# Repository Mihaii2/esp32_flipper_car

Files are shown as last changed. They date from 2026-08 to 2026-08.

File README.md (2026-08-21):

# Flipper Car ROS 2 Workspace

A dual-mode, auto-inverting RC flipper car controlled via ESP32, TC1508 dual H-bridge motor driver, and ROS 2 Jazzy.

<div align="center">
  <table>
    <tr>
      <td align="center" width="33%">
        Live Demo
      </td>
      <td align="center" width="33%">
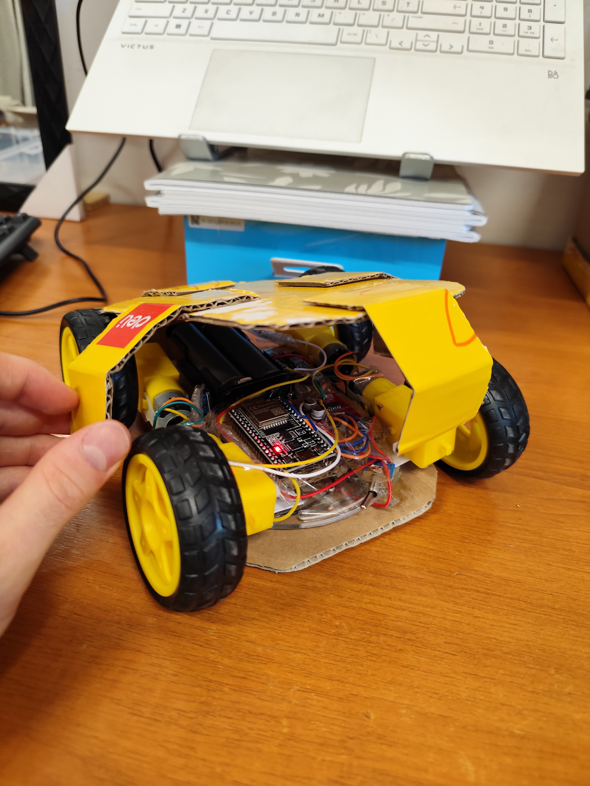
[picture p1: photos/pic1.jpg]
Chassis Top
        
      </td>
      <td align="center" width="33%">
        Chassis Detail
      </td>
    </tr>
  </table>
</div>

> **🛠 Engineering Revision Note (v1.0 → v2.0):**  
> * **v1.0 (Initial Prototype):** Originally designed around discrete low-side N-channel MOSFETs with an experimental SG90 servo-driven mechanical polarity inverter for educational prototyping across the ROS 2 toolchain.  
> * **v2.0 (Current Build):** Upgraded to a dedicated **TC1508 dual H-bridge driver**. The original discrete MOSFETs on hand were standard **`IRFZ44N`** (requiring $V_{GS} \ge 10\text{V}$ for full saturation) rather than logic-level `IRLZ44N` parts. Driving them directly at $3.3\text{V}$ from the ESP32 caused excessive voltage drop and thermal dissipation. Migrating to the TC1508 integrated H-bridge eliminated gate-drive saturation issues, internal flyback diode requirements, and mechanical contact wear while unlocking true zero-radius counter-rotational tank spinning.

---

## 🧩 Bill of Materials (BOM)

### Current Build (v2.0 — Solid-State TC1508 H-Bridge)

| Component / Module | Specification / Model | Qty | Description / Role |
|---|---|---|---|
| **Microcontroller** | ESP32 DevKitC V4 (SuooTci / USB) | 1 | Core logic, FreeRTOS tasks, PWM generation & Micro-ROS bridge |
| **Motor Driver** | TC1508 / MX1508 Dual H-Bridge | 1 | 3.3V logic-compatible dual motor driver ($2.0\text{V} - 9.6\text{V}$, $1.5\text{A}$ peak/ch) |
| **DC Motors** | TT Gearbox DC Motors (3V–9V) | 4 | Drive wheels (2x Left, 2x Right wired in parallel pairs) |
| **Tilt Sensor** | SW-520D Ball Switch | 1 | Detects chassis inversion / rollover state |
| **Power Decoupling Caps**| $470\,\mu\text{F}$ Electrolytic ($\ge 16\text{V}$) | 2 | Bulk filter capacitors (1x on +7.4V battery rail, 1x on +5V logic rail) |
| **Step-Down Regulator**| MP1584EN Buck Converter | 1 | Steps down 7.4V battery input to 5V rail for ESP32 |
| **Battery Power** | 18650 Li-ion cells (2S / 7.4V Nominal) | 2 | Main system power source |

---

### Legacy Prototype (v1.0 — Discrete Gate & Mechanical Polarity Wiper)

| Component / Module | Specification / Model | Qty | Role & Status in Current Build |
|---|---|---|---|
| **Microcontroller** | ESP32 DevKitC V4 | 1 | Retained in v2.0 |
| **DC Motors** | TT Gearbox DC Motors (3V–9V) | 4 | Retained in v2.0 |
| **Step-Down Regulator**| MP1584EN Buck Converter | 1 | Retained in v2.0 |
| **Battery Power** | 18650 Li-ion cells (2S / 7.4V) | 2 | Retained in v2.0 |
| **Tilt Sensor** | SW-520D Ball Switch | 1 | Retained in v2.0 |
| **Power Decoupling Caps**| $470\,\mu\text{F}$ Electrolytic ($\ge 16\text{V}$) | 2 | Retained in v2.0 (Rail decoupling for inductive loads) |
| **MOSFETs** | N-Channel (IRFZ44N) | 2 | **Deprecated:** Standard gate $V_{GS(th)}$ too high for direct 3.3V logic switching. |
| **Servo Motor** | SG90 9g Micro Servo | 1 | **Deprecated:** Mechanical polarity wiper replaced by electronic direction switching. |
| **Flyback Diodes** | 1N4007 | 2 | **Deprecated:** Integrated directly into the TC1508 H-bridge silicon. |
| **Gate Resistors** | 10 kΩ (1/4W) | 2 | **Deprecated:** Unnecessary with driver-level logic inputs. |

---

## 🛠 Features
- **Independent 4-Quadrant Motor Control:** True bidirectional PWM control per side via the TC1508 integrated dual H-bridge.
- **Counter-Rotating Zero-Radius Spins:** Independent forward/reverse driving per track for instant in-place rotation.
- **Auto-Flip Inversion:** SW-520D tilt sensor automatically remaps steering and drive polarities in silicon when the chassis is inverted.
- **Micro-ROS & Native FreeRTOS Integration:** Native ESP-IDF C firmware running micro-ROS (XRCE-DDS) directly over UDP/Wi-Fi to ROS 2 Jazzy.
- **Verified Hardware-in-the-Loop (HIL):** ESP32 silicon executing all kinematic translations, roll inversion math, and closed-loop `/cmd_vel` generation controlling Gazebo/RViz in real time.

---

## 🔌 Hardware Architecture & Circuit Schematic

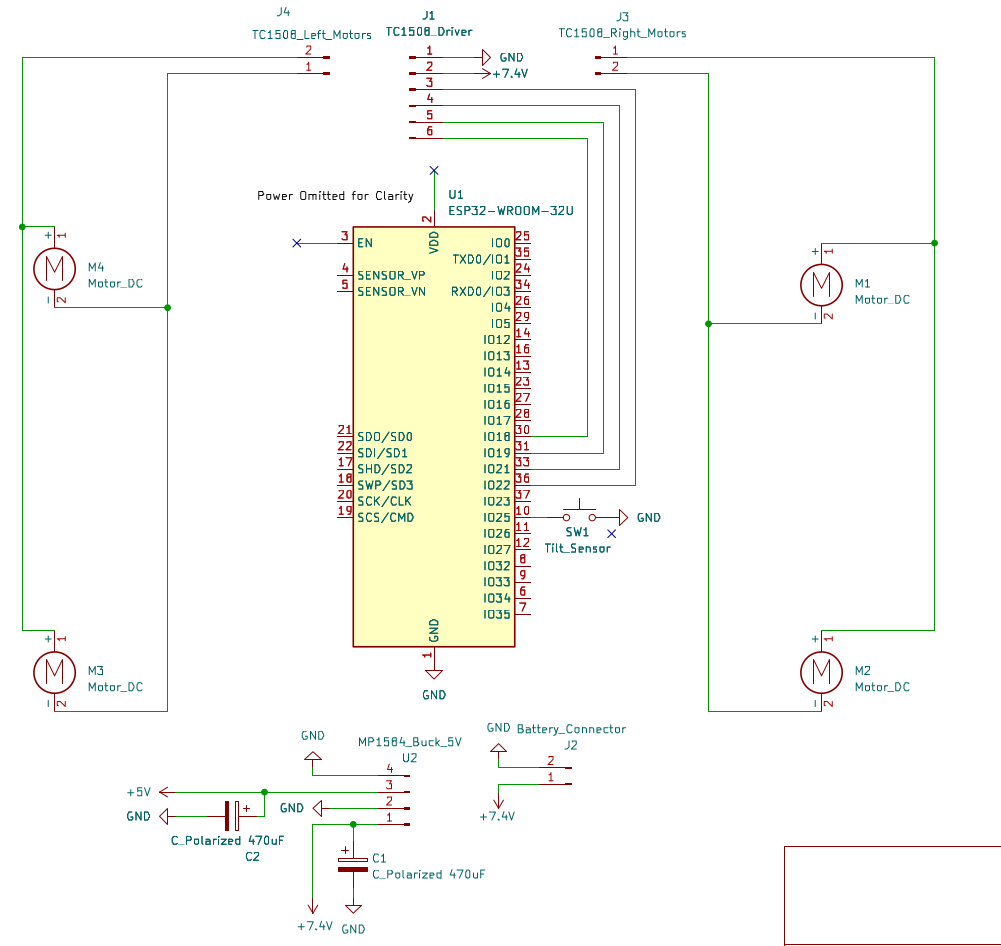
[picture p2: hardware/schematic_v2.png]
Circuit Schematic


> **📌 Schematic Notes:**
> * **Driver Integration:** The TC1508 features integrated internal flyback clamping diodes, eliminating the need for external discrete `1N4007` diodes.
> * **Power Decoupling:** A $470\,\mu\text{F}$ capacitor is tied directly across the battery $+7.4\text{V}$ and $\text{GND}$ rails close to the TC1508 to prevent inductive brownouts on the ESP32.
> * **ESP32 Board-Level Abstraction:** An **ESP32 DevKitC V4** development board is used for the physical build. Onboard power regulation (5V to 3.3V LDO), EN/Boot pull-ups/capacitors, and the USB-UART interface are integrated on the board and omitted from the component-level schematic for clarity.

## 🏗️ Architecture & Dual-Core Execution Model

```mermaid
graph TD
    subgraph Host["HOST LAPTOP (ROS 2 Jazzy / Gazebo)"]
        Teleop["Multi-Key Teleop<br/><code>/flipper/command</code>"]
        Agent["Micro-ROS Agent<br/>(Docker UDP4 Port 8888)"]
        Sim["Gazebo Sim + RViz<br/><code>/imu, /odom, /tf</code>"]
        
        Teleop -->|ROS 2 Topic| Agent
        Agent -->|"/cmd_vel"| Sim
    end

    subgraph ESP32["ESP32 FIRMWARE (ESP-IDF)"]
        subgraph Core0["Core 0: Networking & Middleware"]
            WiFi["lwIP TCP/IP & Wi-Fi PHY<br/>(Priority 23)"]
            uROS["Micro-ROS Client Task<br/>(rmw_microros / Executor)"]
        end

        subgraph Core1["Core 1: Deterministic Real-Time Control"]
            Tilt["SW-520D Filter & Inversion<br/>(500ms Hysteresis Debounce)"]
            PWM["TC1508 Dual-Motor PWM<br/>(1 kHz LEDC Driver)"]
        end
        
        uROS <-->|Thread-Safe State| Core1
    end

    Agent <==>|"802.11 Wi-Fi / UDP<br/>(Micro XRCE-DDS)"| uROS
```

## 🕹️ Teleoperation & Controls

| Key Binding | Action | Actuation Behavior / Setpoint |
|---|---|---|
| `W` / `S` | Drive Forward / Reverse | Both tracks drive symmetrically at active gear speed |
| `A` / `D` | Zero-Radius Tank Spin | Left & right tracks counter-rotate symmetrically |
| `W + A` / `W + D` | Sharp Forward Curves | Outer track at full gear speed; inner track at 35% power |
| `S + A` / `S + D` | Sharp Reverse Curves | Outer track at -100% gear speed; inner track at -35% power |
| *(Release All)* | Auto Coast / Stop | Motors silenced (`0% PWM`) |
| `1` | Gear 1 (Precision / Crawl) | Scaled to **55% PWM** (Deadband compensation) |
| `2` | Gear 2 (Cruise / Street) | Scaled to **75% PWM** |
| `3` | Gear 3 (Turbo / Full) | Scaled to **100% PWM** |
| `Shift` | Turbo Boost | Overrides current gear to **100% PWM** while held |

---

## ⚡ Hardware Pinout (ESP32)

| Component Pin | ESP32 GPIO | Peripheral / Channel | Function / Configuration |
|---|---|---|---|
| **TC1508 `INA` (`IN1`)** | `GPIO 19` | `LEDC_CHANNEL_0` | Motor A Left Inverted Forward |
| **TC1508 `INB` (`IN2`)** | `GPIO 18` | `LEDC_CHANNEL_1` | Motor A Left Inverted Reverse |
| **TC1508 `INC` (`IN3`)** | `GPIO 22` | `LEDC_CHANNEL_2` | Motor B Right Forward |
| **TC1508 `IND` (`IN4`)** | `GPIO 23` | `LEDC_CHANNEL_3` | Motor B Right Reverse |
| **SW-520D Tilt Sensor** | `GPIO 4` | GPIO Input | Inversion Detection (`INPUT_PULLUP`) |

---

## 🚀 Getting Started

### Prerequisites
- Ubuntu 22.04 / 24.04
- ROS 2 (Jazzy / Humble)
- ESP-IDF v5.2+
- Docker (for micro-ROS agent)

### Build & Run
```bash
# Clone and enter workspace
cd ~/ROS_projects/flipper_car_ws

# Build the packages
colcon build --symlink-install

# Source the overlay
source install/setup.bash

# Run using the startup script
./run.sh

# Source ESP-IDF environment (v5.2+)
. $HOME/esp/esp-idf/export.sh

# Navigate to firmware project
cd ~/ROS_projects/flipper_car_ws/firmware/flipper_firmware

# Build, flash to ESP32, and start UART serial monitor
idf.py build flash monitor

docker run -it --rm --net=host microros/micro-ros-agent:jazzy udp4 --port 8888

d ~/ROS_projects/flipper_car_ws
./run.sh
```

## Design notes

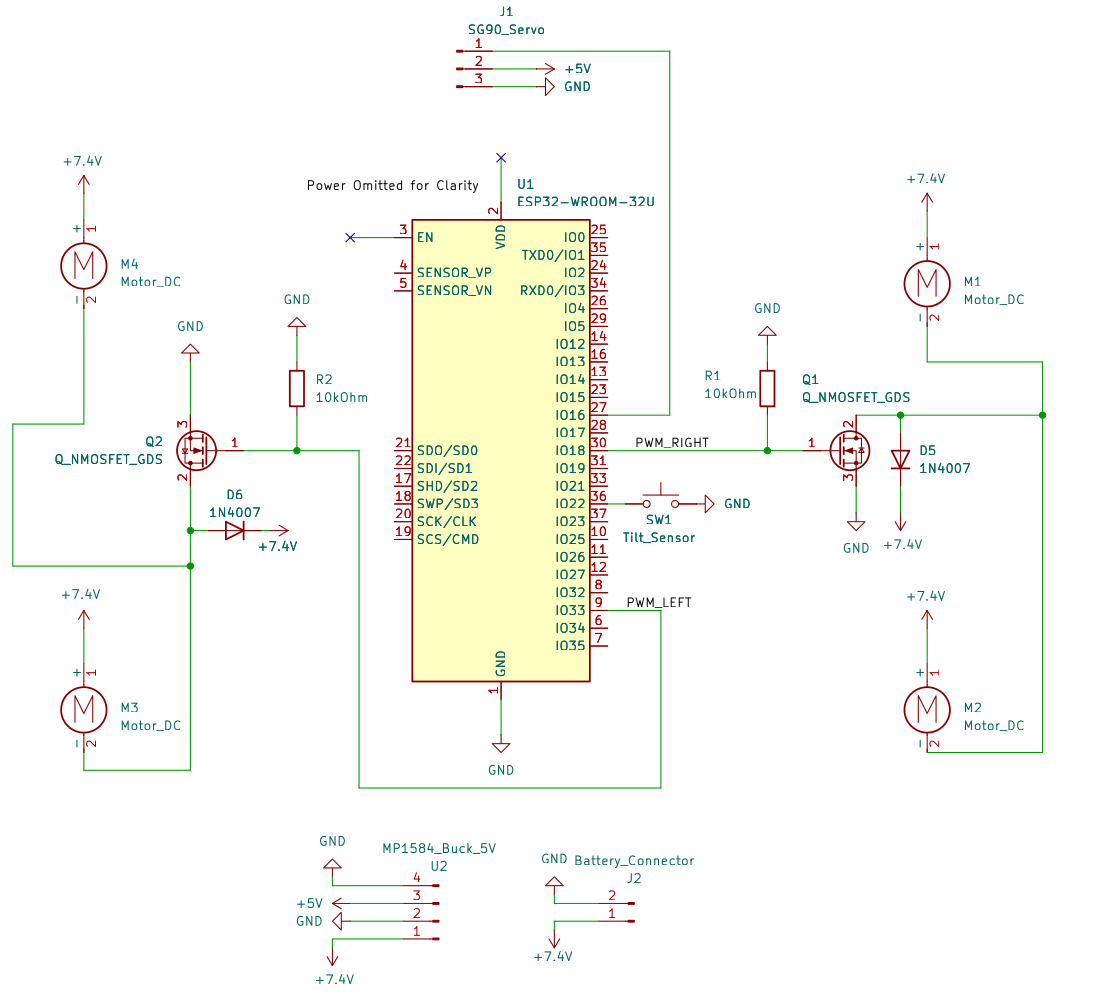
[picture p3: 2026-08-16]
hardware/schematic.png

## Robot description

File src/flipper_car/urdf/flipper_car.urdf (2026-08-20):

<?xml version="1.0"?>
<robot name="flipper_car">

  <!-- Base Link / Chassis -->
  <link name="base_link">
    <inertial>
      <mass value="0.5"/>
      <origin xyz="0 0 0" rpy="0 0 0"/>
      <inertia ixx="0.001" ixy="0" ixz="0" iyy="0.002" iyz="0" izz="0.002"/>
    </inertial>
    
    <!-- Main Body Box -->
    <visual>
      <origin xyz="0 0 0" rpy="0 0 0"/>
      <geometry>
        <box size="0.16 0.10 0.03"/>
      </geometry>
      <material name="blue_mat"><color rgba="0.1 0.3 0.8 1.0"/></material>
    </visual>

    <!-- FRONT NOSE / HEADLIGHT INDICATOR (Visible top and bottom) -->
    <visual>
      <origin xyz="0.075 0 0" rpy="0 0 0"/>
      <geometry>
        <box size="0.015 0.09 0.032"/>
      </geometry>
      <material name="bright_yellow"><color rgba="1.0 0.9 0.0 1.0"/></material>
    </visual>

    <collision>
      <origin xyz="0 0 0" rpy="0 0 0"/>
      <geometry>
        <box size="0.16 0.10 0.03"/>
      </geometry>
    </collision>
  </link>

  <!-- 1. Front Left Wheel (Front Indicator: Orange Hub) -->
  <link name="front_left_wheel">
    <inertial>
      <mass value="0.05"/>
      <origin xyz="0 0 0" rpy="1.5708 0 0"/>
      <inertia ixx="0.0001" ixy="0" ixz="0" iyy="0.0001" iyz="0" izz="0.0001"/>
    </inertial>
    <visual>
      <origin xyz="0 0 0" rpy="1.5708 0 0"/>
      <geometry><cylinder radius="0.04" length="0.025"/></geometry>
      <material name="orange_mat"><color rgba="1.0 0.4 0.0 1.0"/></material>
    </visual>
    <collision>
      <origin xyz="0 0 0" rpy="1.5708 0 0"/>
      <geometry><cylinder radius="0.04" length="0.025"/></geometry>
    </collision>
  </link>
  <joint name="front_left_joint" type="continuous">
    <parent link="base_link"/>
    <child link="front_left_wheel"/>
    <origin xyz="0.05 0.065 0" rpy="0 0 0"/>
    <axis xyz="0 1 0"/>
  </joint>

  <!-- 2. Rear Left Wheel (Black) -->
  <link name="rear_left_wheel">
    <inertial>
      <mass value="0.05"/>
      <origin xyz="0 0 0" rpy="1.5708 0 0"/>
      <inertia ixx="0.0001" ixy="0" ixz="0" iyy="0.0001" iyz="0" izz="0.0001"/>
    </inertial>
    <visual>
      <origin xyz="0 0 0" rpy="1.5708 0 0"/>
      <geometry><cylinder radius="0.04" length="0.025"/></geometry>
      <material name="black_mat"><color rgba="0.1 0.1 0.1 1.0"/></material>
    </visual>
    <collision>
      <origin xyz="0 0 0" rpy="1.5708 0 0"/>
      <geometry><cylinder radius="0.04" length="0.025"/></geometry>
    </collision>
  </link>
  <joint name="rear_left_joint" type="continuous">
    <parent link="base_link"/>
    <child link="rear_left_wheel"/>
    <origin xyz="-0.05 0.065 0" rpy="0 0 0"/>
    <axis xyz="0 1 0"/>
  </joint>

  <!-- 3. Front Right Wheel (Front Indicator: Orange Hub) -->
  <link name="front_right_wheel">
    <inertial>
      <mass value="0.05"/>
      <origin xyz="0 0 0" rpy="1.5708 0 0"/>
      <inertia ixx="0.0001" ixy="0" ixz="0" iyy="0.0001" iyz="0" izz="0.0001"/>
    </inertial>
    <visual>
      <origin xyz="0 0 0" rpy="1.5708 0 0"/>
      <geometry><cylinder radius="0.04" length="0.025"/></geometry>
      <material name="orange_mat"><color rgba="1.0 0.4 0.0 1.0"/></material>
    </visual>
    <collision>
      <origin xyz="0 0 0" rpy="1.5708 0 0"/>
      <geometry><cylinder radius="0.04" length="0.025"/></geometry>
    </collision>
  </link>
  <joint name="front_right_joint" type="continuous">
    <parent link="base_link"/>
    <child link="front_right_wheel"/>
    <origin xyz="0.05 -0.065 0" rpy="0 0 0"/>
    <axis xyz="0 1 0"/>
  </joint>

  <!-- 4. Rear Right Wheel (Black) -->
  <link name="rear_right_wheel">
    <inertial>
      <mass value="0.05"/>
      <origin xyz="0 0 0" rpy="1.5708 0 0"/>
      <inertia ixx="0.0001" ixy="0" ixz="0" iyy="0.0001" iyz="0" izz="0.0001"/>
    </inertial>
    <visual>
      <origin xyz="0 0 0" rpy="1.5708 0 0"/>
      <geometry><cylinder radius="0.04" length="0.025"/></geometry>
      <material name="black_mat"><color rgba="0.1 0.1 0.1 1.0"/></material>
    </visual>
    <collision>
      <origin xyz="0 0 0" rpy="1.5708 0 0"/>
      <geometry><cylinder radius="0.04" length="0.025"/></geometry>
    </collision>
  </link>
  <joint name="rear_right_joint" type="continuous">
    <parent link="base_link"/>
    <child link="rear_right_wheel"/>
    <origin xyz="-0.05 -0.065 0" rpy="0 0 0"/>
    <axis xyz="0 1 0"/>
  </joint>

  <!-- Gazebo Material Colors for Visual Clarity -->
  <gazebo reference="base_link">
    <material>
      <ambient>0.1 0.3 0.8 1.0</ambient>
      <diffuse>0.1 0.3 0.8 1.0</diffuse>
    </material>
  </gazebo>
  <gazebo reference="front_left_wheel">
    <material>
      <ambient>1.0 0.4 0.0 1.0</ambient>
      <diffuse>1.0 0.4 0.0 1.0</diffuse>
    </material>
  </gazebo>
  <gazebo reference="front_right_wheel">
    <material>
      <ambient>1.0 0.4 0.0 1.0</ambient>
      <diffuse>1.0 0.4 0.0 1.0</diffuse>
    </material>
  </gazebo>
  <gazebo reference="rear_left_wheel">
    <material>
      <ambient>0.1 0.1 0.1 1.0</ambient>
      <diffuse>0.1 0.1 0.1 1.0</diffuse>
    </material>
  </gazebo>
  <gazebo reference="rear_right_wheel">
    <material>
      <ambient>0.1 0.1 0.1 1.0</ambient>
      <diffuse>0.1 0.1 0.1 1.0</diffuse>
    </material>
  </gazebo>

  <!-- Ground Friction -->
  <gazebo reference="front_left_wheel"><mu1>1.5</mu1><mu2>1.5</mu2></gazebo>
  <gazebo reference="rear_left_wheel"><mu1>1.5</mu1><mu2>1.5</mu2></gazebo>
  <gazebo reference="front_right_wheel"><mu1>1.5</mu1><mu2>1.5</mu2></gazebo>
  <gazebo reference="rear_right_wheel"><mu1>1.5</mu1><mu2>1.5</mu2></gazebo>

  <!-- Gazebo Skid Steer / Diff Drive Plugin -->
  <gazebo>
    <plugin filename="gz-sim-diff-drive-system" name="gz::sim::systems::DiffDrive">
      <left_joint>front_left_joint</left_joint>
      <left_joint>rear_left_joint</left_joint>
      <right_joint>front_right_joint</right_joint>
      <right_joint>rear_right_joint</right_joint>
      <wheel_separation>0.13</wheel_separation>
      <wheel_radius>0.04</wheel_radius>
      <topic>/cmd_vel</topic>
      <odom_topic>/odom</odom_topic>
      <tf_topic>/tf</tf_topic>
      <frame_id>odom</frame_id>
      <child_frame_id>base_link</child_frame_id>
      <odom_publish_frequency>50</odom_publish_frequency>
    </plugin>

    <!-- Joint State Publisher for Wheel Transforms in RViz -->
    <plugin filename="gz-sim-joint-state-publisher-system" name="gz::sim::systems::JointStatePublisher">
      <topic>/joint_states</topic>
      <joint_name>front_left_joint</joint_name>
      <joint_name>rear_left_joint</joint_name>
      <joint_name>front_right_joint</joint_name>
      <joint_name>rear_right_joint</joint_name>
    </plugin>
  </gazebo>

  <!-- IMU Sensor for Inversion Detection -->
  <gazebo reference="base_link">
    <sensor name="imu_sensor" type="imu">
      <always_on>1</always_on>
      <update_rate>50</update_rate>
      <visualize>false</visualize>
      <topic>/imu</topic>
    </sensor>
  </gazebo>

</robot>

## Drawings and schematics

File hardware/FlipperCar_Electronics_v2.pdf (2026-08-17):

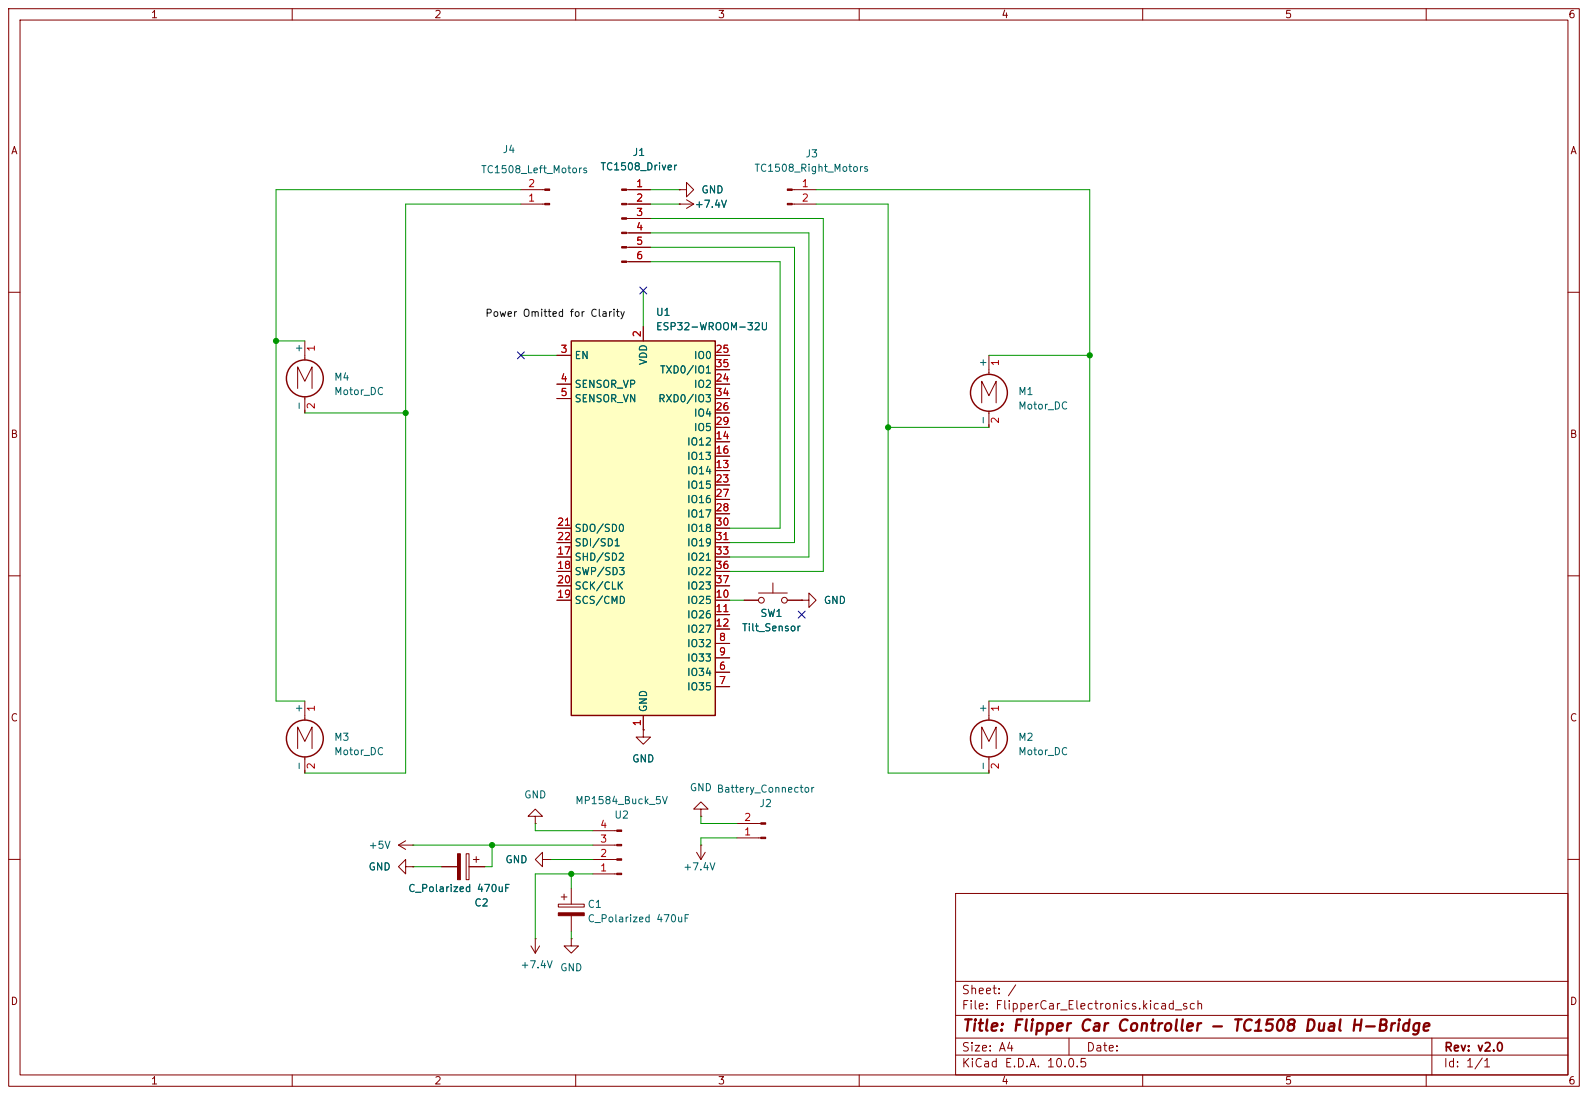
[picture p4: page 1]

Sheet: /
File: FlipperCar_Electronics.kicad_sch
Title: Flipper Car Controller - TC1508 Dual H-Bridge

Size: A4 | Rev: v2.0
KiCad E.D.A. 10.0.5 | Id: 1/1

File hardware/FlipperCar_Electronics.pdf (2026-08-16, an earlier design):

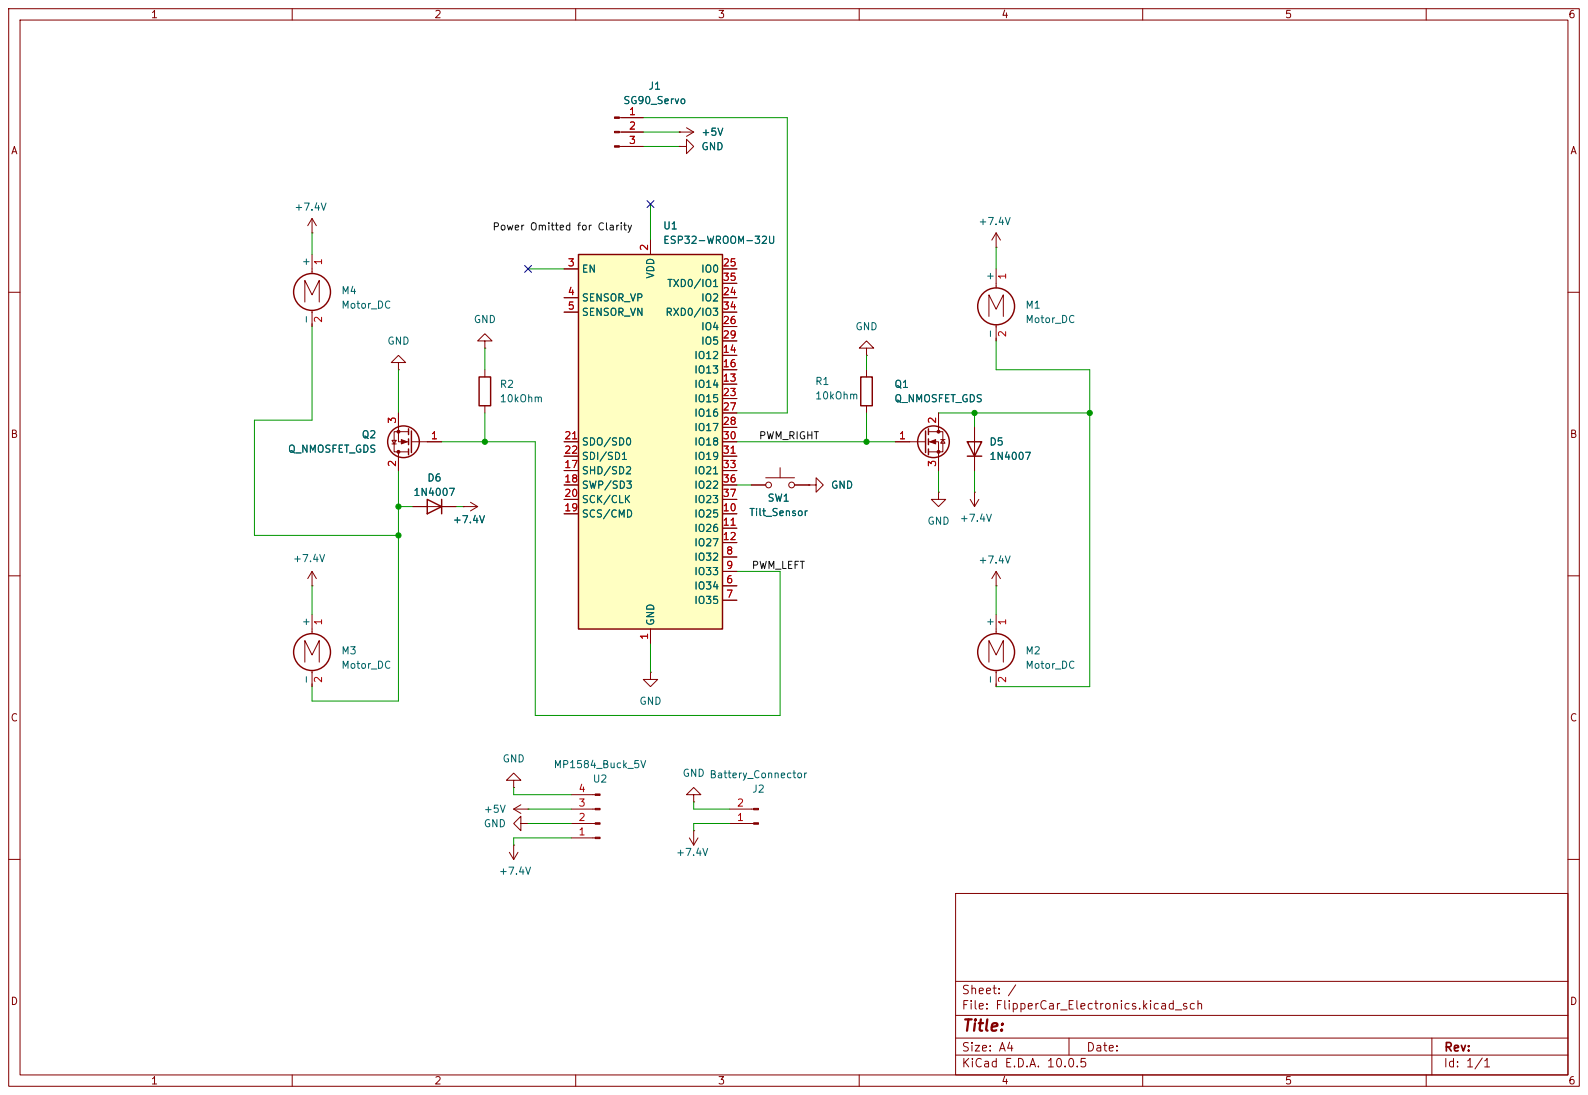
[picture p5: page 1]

Size: A4 | Rev:
KiCad E.D.A. 10.0.5 | Id: 1/1

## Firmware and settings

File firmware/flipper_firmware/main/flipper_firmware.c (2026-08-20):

#include <stdio.h>
#include <string.h>
#include <unistd.h>
#include <sys/socket.h>
#include <netinet/in.h>
#include <arpa/inet.h>

#include "freertos/FreeRTOS.h"
#include "freertos/task.h"
#include "esp_system.h"
#include "esp_wifi.h"
#include "esp_event.h"
#include "esp_log.h"
#include "nvs_flash.h"
#include "driver/ledc.h"
#include "driver/gpio.h"

#include <rcl/rcl.h>
#include <rcl/error_handling.h>
#include <rclc/rclc.h>
#include <rclc/executor.h>
#include <rmw_microros/rmw_microros.h>

#include <geometry_msgs/msg/twist.h>
#include <std_msgs/msg/string.h>

#define TAG "DIGITAL_TWIN_FLIPPER"

#define TARGET_SSID     "laptop_flipper"
#define TARGET_PASS     "mafiosu123"
#define AGENT_IP        "10.42.0.1"
#define AGENT_PORT      "8888"

// Hardware Pin Definitions
#define PIN_IN1         19   // Motor A Left Inverted FWD
#define PIN_IN2         18   // Motor A Left Inverted REV
#define PIN_IN3         22   // Motor B Right FWD
#define PIN_IN4         23   // Motor B Right REV
#define PIN_TILT        4    // SW-520D Tilt Sensor

// PWM Configuration: 1 kHz for solid low-end torque
#define PWM_TIMER       LEDC_TIMER_0
#define PWM_MODE        LEDC_LOW_SPEED_MODE
#define PWM_DUTY_RES    LEDC_TIMER_8_BIT
#define PWM_FREQ_HZ     1000

#define CH_A_FWD        LEDC_CHANNEL_0
#define CH_A_REV        LEDC_CHANNEL_1
#define CH_B_FWD        LEDC_CHANNEL_2
#define CH_B_REV        LEDC_CHANNEL_3

// 25 samples * 20ms = 500ms robust debounce filter
#define WINDOW_SIZE     25 

// Sim velocities
static const float base_speed = 0.5f;
static const float spin_omega = 2.5f;
static const float turn_omega = 2.2f;

#define RCCHECK(fn) { rcl_ret_t temp_rc = fn; if((temp_rc != RCL_RET_OK)){ ESP_LOGE(TAG, "Failed status line %d: %d.",__LINE__,(int)temp_rc); }}
#define RCSOFTCHECK(fn) { rcl_ret_t temp_rc = fn; if((temp_rc != RCL_RET_OK)){ ESP_LOGW(TAG, "Soft fail line %d: %d.",__LINE__,(int)temp_rc);}}

static rcl_publisher_t cmd_vel_pub;
static geometry_msgs__msg__Twist twist_msg;

static char current_command[32] = "STOP";
static volatile float current_gear_multiplier = 0.55f; // Default Gear 1 (55%)
static volatile bool is_upside_down = false;

static EventGroupHandle_t wifi_event_group;
const int WIFI_CONNECTED_BIT = BIT0;

extern uint8_t temprature_sens_read(void);
static float read_esp32_internal_temp(void) {
    return (float)(temprature_sens_read() - 32) / 1.8f;
}

static void force_motors_hard_stop(void) {
    gpio_config_t io_conf = {
        .pin_bit_mask = (1ULL << PIN_IN1) | (1ULL << PIN_IN2) | (1ULL << PIN_IN3) | (1ULL << PIN_IN4),
        .mode = GPIO_MODE_OUTPUT,
        .pull_up_en = GPIO_PULLUP_DISABLE,
        .pull_down_en = GPIO_PULLDOWN_ENABLE,
        .intr_type = GPIO_INTR_DISABLE,
    };
    gpio_config(&io_conf);

    gpio_set_level(PIN_IN1, 0);
    gpio_set_level(PIN_IN2, 0);
    gpio_set_level(PIN_IN3, 0);
    gpio_set_level(PIN_IN4, 0);
}

static void init_hardware(void) {
    gpio_config_t io_conf = {
        .pin_bit_mask = (1ULL << PIN_TILT),
        .mode = GPIO_MODE_INPUT,
        .pull_up_en = GPIO_PULLUP_ENABLE,
        .pull_down_en = GPIO_PULLDOWN_DISABLE,
        .intr_type = GPIO_INTR_DISABLE,
    };
    gpio_config(&io_conf);

    ledc_timer_config_t ledc_timer = {
        .speed_mode       = PWM_MODE,
        .duty_resolution  = PWM_DUTY_RES,
        .timer_num        = PWM_TIMER,
        .freq_hz          = PWM_FREQ_HZ,
        .clk_cfg          = LEDC_AUTO_CLK
    };
    ledc_timer_config(&ledc_timer);

    ledc_channel_config_t ch_cfg[4] = {
        { .channel = CH_A_FWD, .gpio_num = PIN_IN1, .speed_mode = PWM_MODE, .timer_sel = PWM_TIMER, .duty = 0 },
        { .channel = CH_A_REV, .gpio_num = PIN_IN2, .speed_mode = PWM_MODE, .timer_sel = PWM_TIMER, .duty = 0 },
        { .channel = CH_B_FWD, .gpio_num = PIN_IN3, .speed_mode = PWM_MODE, .timer_sel = PWM_TIMER, .duty = 0 },
        { .channel = CH_B_REV, .gpio_num = PIN_IN4, .speed_mode = PWM_MODE, .timer_sel = PWM_TIMER, .duty = 0 }
    };

    for (int i = 0; i < 4; i++) {
        ledc_channel_config(&ch_cfg[i]);
    }
}

static void set_motor_speeds(int left_speed, int right_speed) {
    if (left_speed >= 0) {
        ledc_set_duty(PWM_MODE, CH_A_FWD, left_speed);
        ledc_set_duty(PWM_MODE, CH_A_REV, 0);
    } else {
        ledc_set_duty(PWM_MODE, CH_A_FWD, 0);
        ledc_set_duty(PWM_MODE, CH_A_REV, -left_speed);
    }

    if (right_speed >= 0) {
        ledc_set_duty(PWM_MODE, CH_B_FWD, right_speed);
        ledc_set_duty(PWM_MODE, CH_B_REV, 0);
    } else {
        ledc_set_duty(PWM_MODE, CH_B_FWD, 0);
        ledc_set_duty(PWM_MODE, CH_B_REV, -right_speed);
    }

    ledc_update_duty(PWM_MODE, CH_A_FWD);
    ledc_update_duty(PWM_MODE, CH_A_REV);
    ledc_update_duty(PWM_MODE, CH_B_FWD);
    ledc_update_duty(PWM_MODE, CH_B_REV);
}

void motor_control_task(void *pvParameters) {
    uint32_t temp_ticks = 0;
    uint8_t history[WINDOW_SIZE] = {0};
    int head = 0;
    bool stable_flipped = false;

    while (1) {
        // SW-520D reading
        uint8_t raw = (gpio_get_level(PIN_TILT) == 0) ? 1 : 0;
        history[head] = raw;
        head = (head + 1) % WINDOW_SIZE;

        int votes = 0;
        for (int i = 0; i < WINDOW_SIZE; i++) votes += history[i];

        if (!stable_flipped && votes >= 21) {
            stable_flipped = true;
            ESP_LOGW(TAG, "ORIENTATION -> FLIPPED (UPSIDE DOWN)");
        } else if (stable_flipped && votes <= 4) {
            stable_flipped = false;
            ESP_LOGW(TAG, "ORIENTATION -> NORMAL (UPRIGHT)");
        }
        is_upside_down = stable_flipped;

        if (++temp_ticks >= 250) {
            temp_ticks = 0;
            ESP_LOGI(TAG, "Temp: %.1f °C | Gear: %.0f%% | Flipped: %s", 
                     read_esp32_internal_temp(), current_gear_multiplier * 100.0f, is_upside_down ? "YES" : "NO");
        }

        int full_duty = (int)(255 * current_gear_multiplier);
        int turn_duty = (int)(full_duty * 0.35f);

        int target_left = 0;
        int target_right = 0;

        if (!is_upside_down) {
            // ==========================================
            // === NORMAL (UPRIGHT / FLIPPED: NO) ===
            // ==========================================
            if (strcmp(current_command, "FORWARD") == 0) { 
                target_left = full_duty; 
                target_right = full_duty; 
            } else if (strcmp(current_command, "REVERSE") == 0) { 
                target_left = -full_duty; 
                target_right = -full_duty; 
            } else if (strcmp(current_command, "SPIN_LEFT") == 0) { 
                target_left = full_duty; 
                target_right = -full_duty; 
            } else if (strcmp(current_command, "SPIN_RIGHT") == 0) { 
                target_left = -full_duty; 
                target_right = full_duty; 
            } else if (strcmp(current_command, "FWD_LEFT") == 0) { 
                target_left = full_duty; 
                target_right = turn_duty; 
            } else if (strcmp(current_command, "FWD_RIGHT") == 0) { 
                target_left = turn_duty; 
                target_right = full_duty; 
            } else if (strcmp(current_command, "REV_LEFT") == 0) { 
                target_left = -full_duty; 
                target_right = -turn_duty; 
            } else if (strcmp(current_command, "REV_RIGHT") == 0) { 
                target_left = -turn_duty; 
                target_right = -full_duty; 
            }
        } else {
            // ==========================================
            // === FLIPPED (UPSIDE DOWN / FLIPPED: YES) ===
            // ==========================================
            if (strcmp(current_command, "FORWARD") == 0) { 
                target_left = -full_duty; 
                target_right = -full_duty; 
            } else if (strcmp(current_command, "REVERSE") == 0) { 
                target_left = full_duty; 
                target_right = full_duty; 
            } else if (strcmp(current_command, "SPIN_LEFT") == 0) { 
                target_left = full_duty; 
                target_right = -full_duty; 
            } else if (strcmp(current_command, "SPIN_RIGHT") == 0) { 
                target_left = -full_duty; 
                target_right = full_duty; 
            } else if (strcmp(current_command, "FWD_LEFT") == 0) { 
                // Left curve forward: Left motor full forward (-full), Right motor throttled (-turn)
                target_left = -turn_duty; 
                target_right = -full_duty; 
            } else if (strcmp(current_command, "FWD_RIGHT") == 0) { 
                // Right curve forward: Left motor full forward (-full), Right motor throttled (-turn)
                target_left = -full_duty; 
                target_right = -turn_duty; 
            } else if (strcmp(current_command, "REV_LEFT") == 0) { 
                target_left = turn_duty; 
                target_right = full_duty; 
            } else if (strcmp(current_command, "REV_RIGHT") == 0) { 
                target_left = full_duty; 
                target_right = turn_duty; 
            }
        }

        set_motor_speeds(target_left, target_right);
        vTaskDelay(pdMS_TO_TICKS(20));
    }
}

static void wifi_event_handler(void* arg, esp_event_base_t event_base, int32_t event_id, void* event_data) {
    if (event_base == WIFI_EVENT && event_id == WIFI_EVENT_STA_START) {
        esp_wifi_connect();
    } else if (event_base == WIFI_EVENT && event_id == WIFI_EVENT_STA_DISCONNECTED) {
        xEventGroupClearBits(wifi_event_group, WIFI_CONNECTED_BIT);
        vTaskDelay(pdMS_TO_TICKS(1000));
        esp_wifi_connect();
    } else if (event_base == IP_EVENT && event_id == IP_EVENT_STA_GOT_IP) {
        xEventGroupSetBits(wifi_event_group, WIFI_CONNECTED_BIT);
    }
}

static void wifi_init_sta(void) {
    wifi_event_group = xEventGroupCreate();
    ESP_ERROR_CHECK(esp_netif_init());
    ESP_ERROR_CHECK(esp_event_loop_create_default());
    esp_netif_create_default_wifi_sta();

    wifi_init_config_t cfg = WIFI_INIT_CONFIG_DEFAULT();
    ESP_ERROR_CHECK(esp_wifi_init(&cfg));

    ESP_ERROR_CHECK(esp_event_handler_instance_register(WIFI_EVENT, ESP_EVENT_ANY_ID, &wifi_event_handler, NULL, NULL));
    ESP_ERROR_CHECK(esp_event_handler_instance_register(IP_EVENT, IP_EVENT_STA_GOT_IP, &wifi_event_handler, NULL, NULL));

    wifi_config_t wifi_config = {
        .sta = {
            .ssid = TARGET_SSID,
            .password = TARGET_PASS,
            .threshold.authmode = WIFI_AUTH_WPA2_PSK,
            .pmf_cfg = { .capable = true, .required = false },
        },
    };
    ESP_ERROR_CHECK(esp_wifi_set_mode(WIFI_MODE_STA));
    ESP_ERROR_CHECK(esp_wifi_set_config(WIFI_IF_STA, &wifi_config));
    ESP_ERROR_CHECK(esp_wifi_start());
    ESP_ERROR_CHECK(esp_wifi_set_ps(WIFI_PS_NONE));

    ESP_LOGI(TAG, "Connecting to Laptop Hotspot: %s...", TARGET_SSID);
    xEventGroupWaitBits(wifi_event_group, WIFI_CONNECTED_BIT, pdFALSE, pdTRUE, portMAX_DELAY);
    ESP_LOGI(TAG, "Wi-Fi Connected successfully!");
}

void cmd_callback(const void * msgin) {
    const std_msgs__msg__String * msg = (const std_msgs__msg__String *)msgin;
    if (msg != NULL && msg->data.data != NULL) {
        const char *cmd = msg->data.data;
        // 3-Gear Setup
        if (strcmp(cmd, "GEAR_1") == 0) current_gear_multiplier = 0.55f;      // 55% Low / Precision
        else if (strcmp(cmd, "GEAR_2") == 0) current_gear_multiplier = 0.75f; // 75% Mid / Cruise
        else if (strcmp(cmd, "GEAR_3") == 0) current_gear_multiplier = 1.00f; // 100% High / Turbo
        else {
            strncpy(current_command, cmd, sizeof(current_command) - 1);
            current_command[sizeof(current_command) - 1] = '\0';
        }
    }
}

void sim_timer_callback(rcl_timer_t * timer, int64_t last_call_time) {
    (void) last_call_time;
    if (timer != NULL) {
        float flip = is_upside_down ? -1.0f : 1.0f;
        float scale = current_gear_multiplier;

        memset(&twist_msg, 0, sizeof(geometry_msgs__msg__Twist));

        if (strcmp(current_command, "FORWARD") == 0) twist_msg.linear.x = (base_speed * scale) * flip;
        else if (strcmp(current_command, "REVERSE") == 0) twist_msg.linear.x = -(base_speed * scale) * flip;
        else if (strcmp(current_command, "SPIN_LEFT") == 0) twist_msg.angular.z = (spin_omega * scale) * flip;
        else if (strcmp(current_command, "SPIN_RIGHT") == 0) twist_msg.angular.z = -(spin_omega * scale) * flip;
        else if (strcmp(current_command, "FWD_LEFT") == 0) {
            twist_msg.linear.x = (base_speed * 0.65f * scale) * flip;
            twist_msg.angular.z = (turn_omega * scale) * flip;
        } else if (strcmp(current_command, "FWD_RIGHT") == 0) {
            twist_msg.linear.x = (base_speed * 0.65f * scale) * flip;
            twist_msg.angular.z = -(turn_omega * scale) * flip;
        } else if (strcmp(current_command, "REV_LEFT") == 0) {
            twist_msg.linear.x = -(base_speed * 0.65f * scale) * flip;
            twist_msg.angular.z = -(turn_omega * scale) * flip;
        } else if (strcmp(current_command, "REV_RIGHT") == 0) {
            twist_msg.linear.x = -(base_speed * 0.65f * scale) * flip;
            twist_msg.angular.z = (turn_omega * scale) * flip;
        }

        RCSOFTCHECK(rcl_publish(&cmd_vel_pub, &twist_msg, NULL));
    }
}

void micro_ros_task(void * arg) {
    rcl_allocator_t allocator = rcl_get_default_allocator();
    rclc_support_t support;
    rcl_init_options_t init_options = rcl_get_zero_initialized_init_options();

    RCCHECK(rcl_init_options_init(&init_options, allocator));

    rmw_init_options_t* rmw_options = rcl_init_options_get_rmw_init_options(&init_options);
    RCCHECK(rmw_uros_options_set_udp_address(AGENT_IP, AGENT_PORT, rmw_options));

    while (rmw_uros_ping_agent_options(100, 2, rmw_options) != RMW_RET_OK) {
        ESP_LOGW(TAG, "Waiting for agent at %s:%s...", AGENT_IP, AGENT_PORT);
        vTaskDelay(pdMS_TO_TICKS(1000));
    }

    ESP_LOGI(TAG, "Connected to Agent! Creating nodes...");
    RCCHECK(rclc_support_init_with_options(&support, 0, NULL, &init_options, &allocator));

    rcl_node_t node;
    RCCHECK(rclc_node_init_default(&node, "esp32_digital_twin", "", &support));

    RCCHECK(rclc_publisher_init_best_effort(
        &cmd_vel_pub,
        &node,
        ROSIDL_GET_MSG_TYPE_SUPPORT(geometry_msgs, msg, Twist),
        "/cmd_vel"));

    rcl_subscription_t cmd_sub;
    std_msgs__msg__String cmd_msg;
    char cmd_buffer[32];

    RCCHECK(rclc_subscription_init_best_effort(
        &cmd_sub,
        &node,
        ROSIDL_GET_MSG_TYPE_SUPPORT(std_msgs, msg, String),
        "/flipper/command"));

    cmd_msg.data.data = cmd_buffer;
    cmd_msg.data.capacity = sizeof(cmd_buffer);
    cmd_msg.data.size = 0;

    rcl_timer_t sim_timer;
    RCCHECK(rclc_timer_init_default2(&sim_timer, &support, RCL_MS_TO_NS(50), sim_timer_callback, true));

    rclc_executor_t executor;
    RCCHECK(rclc_executor_init(&executor, &support.context, 4, &allocator));
    RCCHECK(rclc_executor_add_subscription(&executor, &cmd_sub, &cmd_msg, &cmd_callback, ON_NEW_DATA));
    RCCHECK(rclc_executor_add_timer(&executor, &sim_timer));

    ESP_LOGI(TAG, "micro-ROS executor running smoothly!");

    while (1) {
        rclc_executor_spin_some(&executor, RCL_MS_TO_NS(10));
        vTaskDelay(pdMS_TO_TICKS(10));
    }
}

void app_main(void) {
    force_motors_hard_stop();

    nvs_flash_init();
    init_hardware();
    wifi_init_sta();

    xTaskCreatePinnedToCore(motor_control_task, "motor_task", 4096, NULL, 10, NULL, 1);
    xTaskCreatePinnedToCore(micro_ros_task, "uros_task", 4096 * 4, NULL, 5, NULL, 0);
}

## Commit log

2026-08-16 Initial commit: flipper_car ROS 2 workspace
    [flipper_car.urdf]
2026-08-16 Add hardware documentation and kicad schematic images
    [FlipperCar_Electronics.kicad_sch]
2026-08-17 added the simulation for v1 car with flipping controls reversion logic checked
    [FlipperCar_Electronics_v1_legacy.kicad_sch, FlipperCar_Electronics_v2.kicad_sch]
2026-08-17 added rviz & gazebo sim for v2.0 car
    [flipper_car.urdf]
2026-08-20 physical car assembled, running on its own now connected to laptop's WIFI hotspot
    [flipper_car.urdf]
